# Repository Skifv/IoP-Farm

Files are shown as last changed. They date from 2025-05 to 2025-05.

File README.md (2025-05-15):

# IoP-Farm (Internet of Plants Farm)

## Проектная документация

### Содержание
1. [Задача проекта](#задача-проекта)
2. [Описание решения](#описание-решения)
3. [Аппаратная часть](#аппаратная-часть)
   - [Компоненты](#компоненты)
   - [Схема подключения](#схема-подключения)
4. [Программная часть](#программная-часть)
   - [Архитектура](#архитектура)
   - [Основные модули](#основные-модули)
5. [Производство](#производство)
   - [Использованные инструменты и оборудование](#использованные-инструменты-и-оборудование)
   - [Процесс сборки](#процесс-сборки)
6. [Трудности и проблемы](#трудности-и-проблемы)
7. [Результаты](#результаты)
8. [Дальнейшее развитие](#дальнейшее-развитие)

## Задача проекта

Создание компактной автоматизированной умной фермы для выращивания сельскохозяйственных культур с возможностью удаленного мониторинга и управления через мобильное приложение. Система должна обеспечивать автоматический полив, контроль микроклимата, освещения и передачу данных в режиме реального времени.

## Описание решения

IoP-Farm (Internet of Plants Farm) представляет собой полностью автоматизированную мини-ферму на базе микроконтроллера ESP32, объединяющую аппаратную и программную части в единую экосистему для выращивания растений.

Основные функциональные возможности:

- **Автоматический полив**: система на основе данных о влажности почвы и расписания включает насос R385, который подает воду в количестве, необходимом конкретной культуре.

- **Контроль температуры**: датчики DHT22 и DS18B20 следят за температурой воздуха и почвы, а система автоматически включает тепловую лампу при падении температуры ниже заданного порога.

- **Управление освещением**: фитолента включается и выключается по заданному расписанию, обеспечивая оптимальный световой режим для растений.

- **Мониторинг уровня воды**: ультразвуковой датчик HC-SR04 контролирует уровень воды в резервуаре, предупреждая о необходимости его пополнения.

- **WiFi и MQTT-интеграция**: система подключается к домашней сети WiFi и отправляет данные на MQTT-сервер, что позволяет управлять фермой удаленно.

- **Мобильное приложение**: специальное Android-приложение позволяет в реальном времени мониторить все показатели, менять настройки и управлять исполнительными устройствами.

## Аппаратная часть

### Компоненты

#### Микроконтроллер
- **ESP32 WROOM 32**: 32-битный двухъядерный микроконтроллер с WiFi и Bluetooth, 4 МБ Flash-памяти, 520 КБ SRAM

#### Датчики
- **DHT22**: цифровой датчик температуры и влажности воздуха
- **DS18B20**: цифровой датчик температуры с водонепроницаемым корпусом для измерения температуры почвы
- **HC-SR04**: ультразвуковой датчик расстояния для контроля уровня воды в резервуаре
- **FC-28**: аналоговый датчик влажности почвы
- **KY-018**: фоторезистор для определения уровня освещенности
- **YFS401**: датчик расхода воды (расходомер)

#### Исполнительные устройства
- **Насос R385**: водяной насос для полива растений
- **Тепловая лампа**: для поддержания нужной температуры воздуха
- **Фитолента (LED)**: специализированное освещение для оптимального роста растений

#### Блок питания
- **12V адаптер питания** для ESP32 через DC-Jack, насоса и всех остальных устройств при помощи DC-DC преобразователей.

#### Корпус
- Корпус из прозрачного акрилового стекла (оргстекла) толщиной 6 мм
- 3D-печатные крепления и держатели для датчиков и актуаторов
- Ведро для воды, помещенное в пластиковую тонкую оболочку

Альтернативный текст

### Схема подключения

Датчики и актуаторы подключены к ESP32 согласно схеме, описанной в файле схемы и в заголовочных файлах исходного кода. 

## Программная часть

### Архитектура

Программное обеспечение IoP-Farm построено на принципах объектно-ориентированного программирования и модульной архитектуры. Это позволяет легко расширять функциональность и добавлять новые компоненты без изменения основной структуры - стандартные принципы ООП.

### Основные модули

1. **Датчики (sensors)**: Абстракция всех датчиков через интерфейс `ISensor`, который определяет единый метод получения данных. Каждый датчик реализован как отдельный класс, наследующийся от базового интерфейса.

2. **Актуаторы (actuators)**: Все исполнительные устройства реализованы через интерфейс `IActuator`. Включает в себя насос, тепловую лампу и фитоленту.

3. **Стратегии (strategies)**: Определяют логику работы актуаторов на основе данных от датчиков и расписания. Реализованы стратегии полива, нагрева и освещения. Позволяют легко масшабировать систему и являются основой нашей экосистемы.

4. **Менеджеры (managers)**:
   - **WiFiManager**: Управление WiFi-соединением, создание точки доступа при необходимости
   - **MQTTManager**: Подключение к MQTT-брокеру, отправка/получение сообщений
   - **ConfigManager**: Управление конфигурацией в SPIFFS, загрузка дефолтных настроек
   - **OTAManager**: Обеспечение обновления прошивки по воздуху
   - **WebServerManager**: Веб-интерфейс для конфигурации

5. **Логирование**: Система логирования с различными уровнями, форматтерами и транспортами (Serial, MQTT).

6. **Мобильное приложение**: Android-приложение для управления фермой, разработанное на Java, взаимодействующее с системой через MQTT.

## Производство

### Использованные инструменты и оборудование

- **3D-принтеры** для изготовления креплений, держателей и функциональных деталей
- **Лазерные резаки** для точной обработки акрилового стекла
- **Паяльная станция** для монтажа электронных компонентов
- **Струбцины** для склейки оргстекла дихлорэтаном
- **Ручной инструмент** (отвертки, плоскогубцы, кусачки и т.д.)
- **Мультиметр** для тестирования электрических цепей

## Трудности и проблемы

В процессе разработки и реализации проекта мы столкнулись с несколькими серьезными проблемами:

1. **Проблемы с 3D-печатью**: Постоянно приходилось переставлять 3D-принтеры на печать из-за проблем с первым слоем. Это значительно замедлило процесс изготовления деталей и корпуса.

2. **Ограничения пуш-уведомлений**: Не удалось реализовать пуш-уведомления на Android из-за того, что они зависят от сервисов Google Firebase Cloud Messaging (FCM), доступ к которым ограничен в России из-за санкций. Android запрещает фоновым приложениям выполнять определенные действия, если они не используют официальные API Google.

3. **Трудности с микроконтроллерами**: Изначально проект планировалось реализовать на STM32, но из-за отмены курса по микроконтроллерам и отсутствия достаточного опыта работы с ними, более двух недель ушло на попытки настроить STM32. В итоге было принято решение перейти на более удобную в разработке платформу ESP32.

4. **Интеграция аппаратной и программной частей**: Потребовалось много времени на отладку взаимодействия между датчиками, ESP32 и исполнительными устройствами, особенно в части обработки ошибок и надежности системы.

## Результаты

В результате проекта была создана полностью функциональная автоматизированная мини-ферма с возможностью удаленного управления. Система обеспечивает:

- Полностью автоматический полив на основе показаний датчиков влажности почвы
- Контроль и поддержание температуры окружающей среды
- Управление освещением по расписанию
- Удобный мониторинг всех показателей через мобильное приложение
- Возможность ручного управления всеми исполнительными устройствами
- Настройку и конфигурирование системы без необходимости физического доступа к устройству

## Дальнейшее развитие

Планы по дальнейшему развитию проекта включают:

1. **Масштабирование системы** для поддержки нескольких ферм с централизованным управлением
2. **Расширение набора датчиков** (pH почвы, CO2, содержание минералов)
3. **Улучшение** внешнего вида приложения

---

Проект IoP-Farm демонстрирует, как современные технологии могут быть применены для решения практических задач в области сельского хозяйства и домашнего растениеводства, обеспечивая оптимальные условия выращивания с минимальным участием человека.

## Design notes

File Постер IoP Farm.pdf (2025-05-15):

# IoP Farm

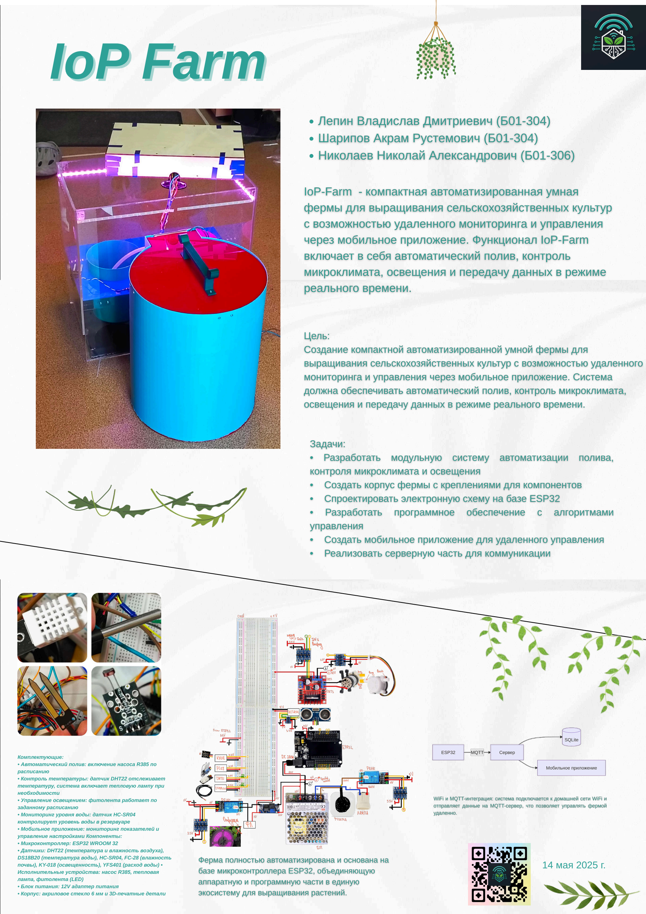
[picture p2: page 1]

14 мая 2025 г.

Комплектующие:

- Автоматический полив: включение насоса R385 по

расписанию

- Контроль температуры: датчик DHT22 отслеживает

температуру, система включает тепловую лампу при

необходимости

- Управление освещением: фитолента работает по

заданному расписанию

- Мониторинг уровня воды: датчик HC-SR04

контролирует уровень воды в резервуаре

- Мобильное приложение: мониторинг показателей и

управление настройками Компоненты:

- Микроконтроллер: ESP32 WROOM 32
- Датчики: DHT22 (температура и влажность воздуха),

DS18B20 (температура воды), HC-SR04, FC-28 (влажность

почвы), KY-018 (освещенность), YFS401 (расход воды) •

Исполнительные устройства: насос R385, тепловая

лампа, фитолента (LED)

- Блок питания: 12V адаптер питания
- Корпус: акриловое стекло 6 мм и 3D-печатные детали

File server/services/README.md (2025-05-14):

Ключевые возможности
- Сбор данных с ESP32-устройств в реальном времени
- Хранение в локальной БД (data.db) с историей показаний
- Интерфейс API на основе TCP и MQTT, включает:
    - Логирование в syslog и файлы (/var/log/)
    - Автозапуск через systemd

```mermaid
graph TD
    A[Датчики ESP32] -->|MQTT| B(MQTT-брокер)
    B --> C[IoP-Server]
    C --> D[(SQLite БД)]
    
    C --> F[TCP API]
    
    F --> G

```

Также необходимо запустить mqtt-server(например mosquitto) на 1883, а также снять ограничения файервола.

Службы сервера:
- data.service (services/data_server_farm/) 
    - Подписывается на топик /farm$id$/data
    - Записывает данные от MQTT-брокера в БД(data.db)
- logger.service (services/farm_logger/)
    - Подписывается на топик /farm$id$/log
    - Записывает данные от MQTT-брокера в syslog
    - Для просмотра логов:
- logs.service (/services/logs_to_phone/)
    - Пересылает на мобильное устройство отчёт по всем показаниям фермы
    - Отправляются все отчёты, удовлетворяющие показателям "unix_time_from" - "unix_time_to"
    - В случае ошибок, неправильного формата, отправляется последняя запись
    - Для просмотра логов:
- config.service (/services/control_phone_config)
    - Принимает подключение от мобильного устройства, получает конфиг параметров сенсоров
    - Публикует в топик /farm$id$/config
- command.service (services/command_services)
    - Принимает подключение от мобильного устройства, получает команду, к-ую срочно нужно обработать на ферме
    - Публикует в топик /farm$id$/command
    
Просмотр логов одной конкретной службы:
```sh
journalctl -u $name$.service
```

Просмотреть статус + логи/добавление в автозагрузку/удаление/старт/остановка конкретной службы:
```sh
systemctl status/enable/disable/start/stop $name$.service
```

Сделать для всех служб сразу:
```sh
./farmctl status/enable/disable/start/stop
```
ВАЖНО!
Если службы НЕ РАБОТАЮТ/ОСТАНОВЛЕНЫ можно запустить вручную бинарные файлы(ОПАСНО):
В папке необходимой службы запускаем компиляцию(sh файл) и исполняем:
```sh
sh data.sh/logger.sh/logs.sh/config.sh/command.sh

# Без прикрепления к commandline в фоновом режиме
nohup DATA/LOGGER/LOGS/CONFIG/COMMAND &
```
Либо же централизовано в папке services компиляция + исполнение:
```sh
sh compile_and_run.sh
```
Удаление фоновых процессов:
```sh
sh delete_trash.sh
```

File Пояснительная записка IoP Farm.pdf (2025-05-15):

## Краткая пояснительная записка к проекту

## “Компактная умная ферма с WiFi-управлением”

## 1 Состав проектной команды и вклад участников

- Лепин Владислав Дмитриевич (Б01-304) — программирование ESP32, разработка

архитектуры программной части, пайка, проектирование и сборка схемы, подготовка презентации, дизайн корпуса.

- Шарипов Акрам Рустемович (Б01-304) — разработка Android-приложения на Java,

проектирование всех 2D и 3D моделей, пайка электронных компонентов.

- Николаев Николай Александрович (Б01-306) — разработка серверной части для

коммуникации между фермой и приложением, сборка конструкции фермы.

## 2 Причины выбора проекта

Основная мотивация — создание практически полезного устройства для повседневного использования, а не просто демонстрационного прототипа. Автоматизированная ферма решает практическую задачу обеспечения растений оптимальными условиями с минимальным участием человека. Проект позволил применить знания из программирования, электроники и 3D-моделирования.

## 3 Цель и задачи проекта

Цель: создание компактной автоматизированной умной фермы для выращивания сельскохозяйственных культур с возможностью удаленного мониторинга и управления через мобильное приложение. Система должна обеспечивать автоматический полив, контроль микроклимата, освещения и передачу данных в режиме реального времени.
Задачи:
- Разработать модульную систему автоматизации полива, контроля микроклимата и освещения
- Создать корпус фермы с креплениями для компонентов
- Спроектировать электронную схему на базе ESP32
- Разработать программное обеспечение с алгоритмами управления
- Создать мобильное приложение для удаленного управления
- Реализовать серверную часть для коммуникации

## 4 Описание продукта

IoP-Farm (Internet of Plants Farm) — автоматизированная мини-ферма на базе ESP32

с функциями:

- Автоматический полив: включение насоса R385 по расписанию
- Контроль температуры: датчик DHT22 отслеживает температуру, система включает тепловую лампу при необходимости
- Управление освещением: фитолента работает по заданному расписанию
- Мониторинг уровня воды: датчик HC-SR04 контролирует уровень воды в резервуаре
- Мобильное приложение: мониторинг показателей и управление настройками

Компоненты:

- Микроконтроллер: ESP32 WROOM 32
- Датчики: DHT22 (температура и влажность воздуха), DS18B20 (температура воды), HC-SR04, FC-28 (влажность почвы), KY-018 (освещенность), YFS401 (расход воды)
- Исполнительные устройства: насос R385, тепловая лампа, фитолента (LED)
- Блок питания: 12V адаптер питания
- Корпус: акриловое стекло 6 мм и 3D-печатные детали

## 5 Процесс решения поставленных задач

### 5.1 Программная часть

Программное обеспечение построено на принципах ООП и модульной архитектуры:

- Датчики: абстракция через интерфейс ISensor
- Актуаторы: все устройства реализованы через интерфейс IActuator
- Стратегии: определяют логику работы на основе данных от датчиков
- Менеджеры: WiFiManager, MQTTManager, ConfigManager, OTAManager, WebServerManager, SensorsManager, ActuatorsManager
- Мобильное приложение: Java-приложение для Android, взаимодействующее через сервер по TCP. Сервер взаимодействует с фермой по MQTT

Все менеджеры, взаимодействуя между собой, управляют работой фермы.
Исходный код проекта доступен в репозитории: https://github.com/Skifv/IoP-Farm

### 5.2 Аппаратная часть

Плоские детали корпуса изготовлены лазерной резкой акрилового стекла, сложные формы — 3D-печатью. Соединение деталей выполнено дихлорэтаном с фиксацией струбцинами. Электронные компоненты соединены по разработанной схеме и подсоединены к ESP32.
Все спроектированные модели доступны в репозитории: https://github.com/Skifv/

IoP-Farm (https://github.com/Skifv/IoP-Farm)

## 6 Анализ существующих аналогов

Найденные нами аналоги имели схожий функционал, но небольшие различия: наличие/отсутствие полива/обогрева/освещения по расписанию/команде. Также в некоторых

отсутствует контроль уровня воды или расхода воды. В одном из аналогов есть камера и визуальный контроль растений.
Отличительные особенности нашего проекта:
- Комплексная автоматизация: полив, обогрев и освещение в одной системе. Ни один из найденных нами аналогов не включал такого разнообразия компонентов
- Контроль расхода воды для точного полива заданного объема. В остальных проектах полив осуществляется на заданный интервал времени, что, безусловно, имеет большие минусы
- Модульная архитектура, позволяющая легко расширять функциональность
- Возможность OTA-обновления программного обеспечения

Здесь можно найти проанализированные аналоги:
1. https://github.com/sunny-zuo/smart-garden
2. https://github.com/fruxefarms/FruxePi
3. https://github.com/PatrickHallek/automated-irrigation-system

## 7 Процесс проектирования и изготовления

Процесс создания IoP-Farm включает в себя 3 этапа (то, что программирование находится на третьем месте, не определяет его порядок):

1. Проектирование:
- Разработка архитектуры системы, определение компонентов
- Проектирование электрической схемы подключения
- Моделирование деталей корпуса в FreeCAD и 3D-моделей в Компас 3D

2. Изготовление:
- Лазерная резка акрилового стекла, 3D-печать креплений
- Сборка корпуса с использованием дихлорэтана
- Монтаж электронных компонентов и пайка
3. Программирование:
- Разработка ПО для ESP32 на C++
- Создание Android-приложения на Java
- Разработка сервера на C++
- Настройка MQTT-брокера

## 8 Процесс тестирования и его результаты

Тестирование проводилось при помощи разработанной системы дистанционного логирования процессов, происходящих на микроконтроллере.
Использовались команды с мобильного приложения и анализировались логи от фермы через сервер. Результаты показали стабильную работу системы:
- Полив активируется при помощи команд, расписание работает корректно
- Система освещения и обогрева работают согласно выстроенным настройкам
- Показания датчиков корректно отображаются в приложении

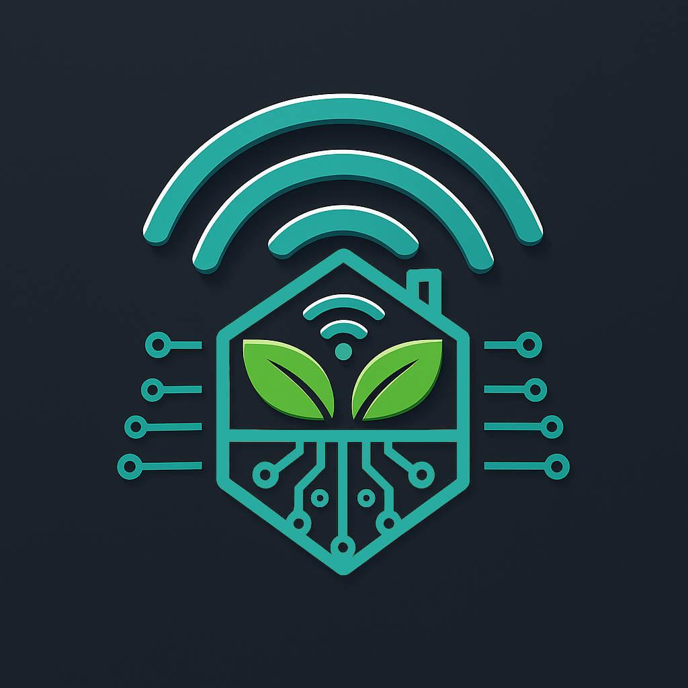
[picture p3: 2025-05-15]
Логотип.png

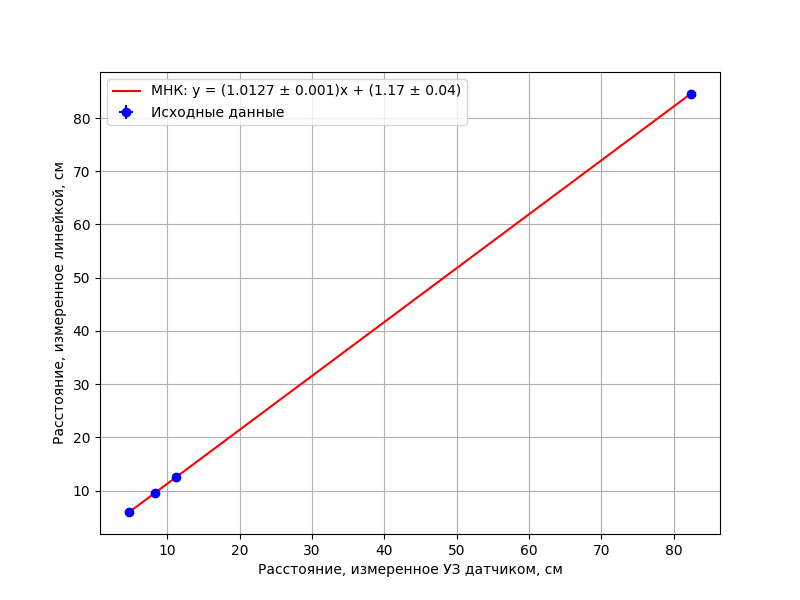
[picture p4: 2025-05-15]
Калибровка ультразвукового датчика.png

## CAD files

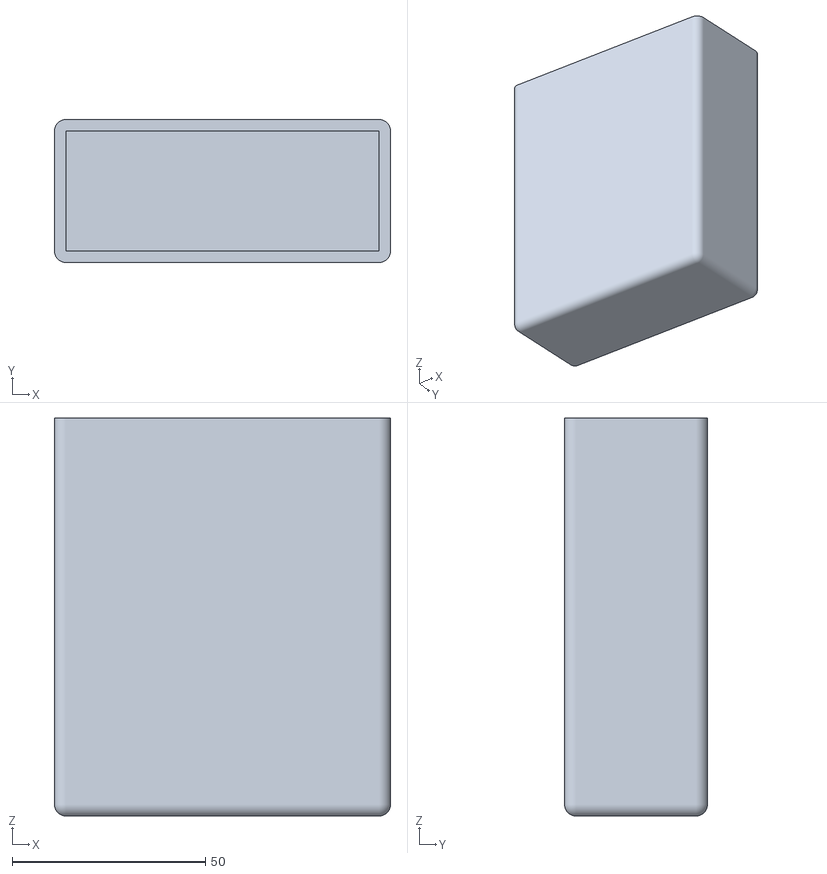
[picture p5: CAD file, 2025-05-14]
3DP_and_laser/transkeeper.stl
87.0 x 37.0 x 103.0

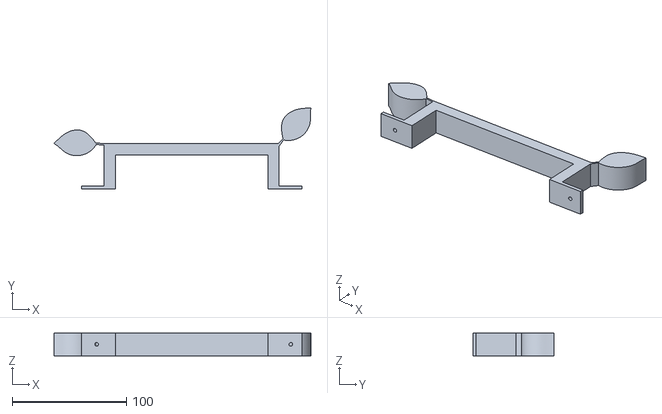
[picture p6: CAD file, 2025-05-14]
3DP_and_laser/handhold.stl
225.1 x 71.3 x 20.0

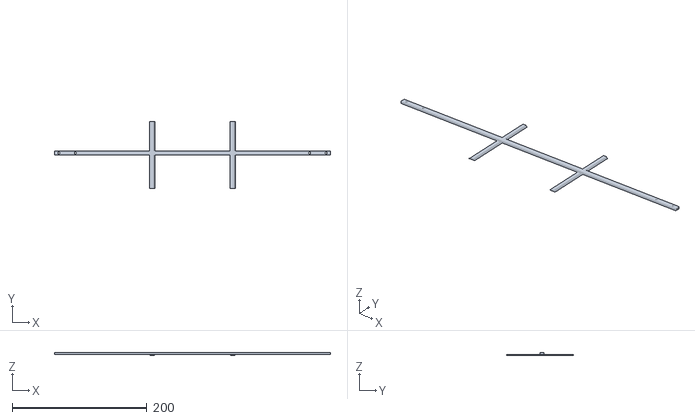
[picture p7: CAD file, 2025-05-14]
3DP_and_laser/rails.stl
410.0 x 100.0 x 5.00

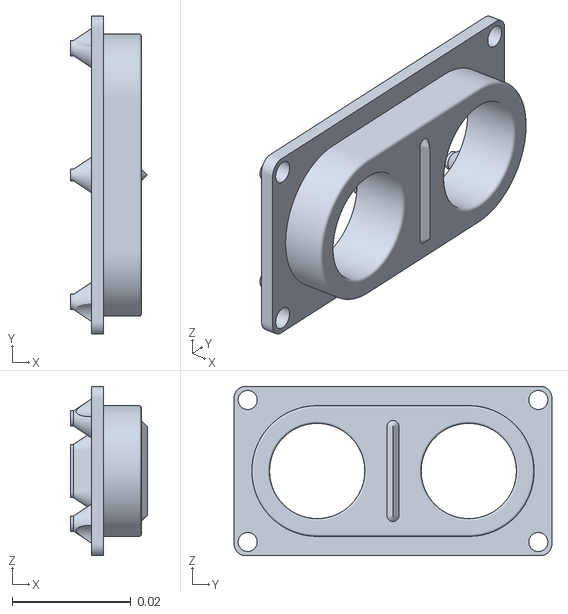
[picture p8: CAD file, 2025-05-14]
3DP_and_laser/HC-SR04_holder.stl
0.0129 x 0.0535 x 0.0285

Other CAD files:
3DP_and_laser/farmbox.stl

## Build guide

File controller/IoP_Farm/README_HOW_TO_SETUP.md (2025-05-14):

# IoP-Farm: Умная автоматизированная ферма на ESP32

**Версия:** 1.0  
**Дата:** 10.05.2025

---

## Оглавление

- [О проекте](#о-проекте)
- [Краткие возможности](#краткие-возможности)
- [Быстрый старт: PlatformIO environments и первичная загрузка](#быстрый-старт-platformio-environments-и-первичная-загрузка)
- [Архитектура и основные компоненты](#архитектура-и-основные-компоненты)
- [Изменяемые параметры в constants.h](#изменяемые-параметры-в-constantsh)
- [Сервер-посредник и хранение данных](#сервер-посредник-и-хранение-данных)
- [Управление с телефона и мониторинг через Android-приложение IoP Farm](#управление-с-телефона-и-мониторинг-через-android-приложение-iop-farm)
- [OTA-обновления](#ota-обновления)
- [Масштабирование и расширение](#масштабирование-и-расширение)
- [Безопасность](#безопасность)
- [FAQ и советы](#faq-и-советы)
- [Важные замечания](#важные-замечания)
- [Контакты и поддержка](#контакты-и-поддержка)

---

## О проекте

**IoP-Farm** — это модульная система для автоматизации полива домашних растений на базе ESP32. Система поддерживает работу с различными датчиками и исполнительными устройствами, интеграцию с WiFi/MQTT, удаленное управление и обновление прошивки по воздуху (OTA). Проект ориентирован на максимальную надежность, расширяемость и простоту первичной настройки.

---

## Краткие возможности

- Автоматический полив по расписанию и объему воды
- Контроль температуры и автоматическое управление нагревом
- Управление освещением по расписанию
- Поддержка WiFi 2.4 ГГц (WPA2/WPA3, STA и точка доступа) для управления с телефона.
- MQTT-интеграция для сбора данных и управления
- Гибкая система конфигурирования (web-интерфейс, WiFiManager, настройка с приложения на Android)
- OTA-обновления (PlatformIO, web-интерфейс, WiFiManager)
- Логирование (Serial, MQTT)
- Модульная архитектура: легко добавлять новые датчики, актуаторы, стратегии
- Хранение всех настроек в энергонезависимой памяти (SPIFFS), автоматическая загрузка последних/дефолтных конфигов в зависимости флага компиляции
- Безопасность: аутентификация web-интерфейса при загрузки прошивки по OTA
- Масштабируемость: поддержка новых топиков MQTT, датчиков и актуаторов, стратегий работы

---

## Быстрый старт: PlatformIO environments и первичная загрузка

### Как устроен platformio.ini

В проекте определено несколько сред (environments) для разных сценариев работы и отладки. Это позволяет гибко управлять процессом прошивки, конфигурирования и обновления устройства.

#### Основные environments:

- `[env:esp32doit-devkit-v1]` — **Штатный режим без лишних логов**. Используется для финальной эксплуатации, когда не требуется подробная отладка.
- `[env:debug]` — **Режим с подробным логированием** (рекомендуется для разработки и диагностики). Выводит максимум информации в Serial и MQTT.
- `[env:load_default_configs]` — **Первичная загрузка**. Используется только при первом запуске нового микроконтроллера или для сброса к заводским настройкам. Загружает дефолтные конфиги и включает расширенное логирование.
- `[env:debugOTA_320WiFi5]`, `[env:debugOTAVenom]` — **OTA-обновления через PlatformIO**. Примеры для разных сетей. Для своей сети скопируйте любой из этих блоков, поменяйте `upload_port` на IP вашей ESP32 в локальной сети, к которой она подключается и (если вы выставили нестандартный пароль) `upload_flags` с новым паролем.

Выбор environment происходит на панели управления platformio.ini в нижней части экрана.

#### Пример добавления своей среды для OTA:

```ini
[env:debugOTA_MyNetwork]
platform = espressif32
board = esp32doit-devkit-v1
framework = arduino
upload_protocol = espota
upload_port = <IP_ESP32>
upload_flags = 
    --auth=<ваш_пароль>
; остальные параметры аналогичны debug
```

Для загрузки прошивки по ArduinoOTA через созданную среду необходимо выставить в настройках platformio.ini (на панели управления в нижней части экрана) в качестве порта локальный IP ESP32 в вашей сети, компьютер при этом тоже должен быть подключен к тому же WiFi. Если все было выставлено, убедитесь, что ESP32 подключен к данному WiFi и загрузите прошивку, нажав Upload на панели управления platformio.ini.

### Порядок действий при первичной загрузке

1. **Клонируйте репозиторий и установите PlatformIO.**
2. **Загрузка файлов конфигурации в SPIFFS**
   - После любой смены конфигов или при первом запуске обязательно загрузите все файлы из папки `data/` на ESP32:
     ```
     pio run --target uploadfs
     ```
   - Это создаст в SPIFFS все необходимые конфиги (`data.json`, `config.json`, `mqtt.json`, `passwords.json` и их дефолтные версии).
3. **Загрузка дефолтных конфигов**
   - Перед началом работы необходимо загрузить файлы из папки `data/` в энергонезависимую память SPIFFS. См. пункт 2.
   - Затем обязательно используйте `[env:load_default_configs]` для самой первой прошивки нового микроконтроллера.
   - Это обеспечит корректную инициализацию всех файлов настроек во Flash.
   - После этого рекомендуется сразу перейти на `[env:debug]` для дальнейшей работы. 
4. **Подключитесь к точке доступа ESP32 и настройте WiFi/MQTT через портал.**
5. **Проверьте работу системы через приложение IoP Farm.**

**Перепрошивка**
   - Для обычной перепрошивки используйте `[env:debug]` (рекомендуется) или `[env:esp32doit-devkit-v1]` (минимум логов).
   - Для OTA-обновлений используйте соответствующую OTA-среду или создайте свою.
   - Для других способов перепрошивки (по сети) см. раздел `OTA Обновления`.

---

## Архитектура и основные компоненты

### Датчики и исполнительные устройства

- **Датчики**: DHT22 (температура и влажность), DS18B20 (температура), HC-SR04 (уровень воды), FC-28 (влажность почвы), KY-018 (освещенность), YFS401 (расход воды).
- **Актуаторы**: насос R385, тепловая лампа, фитолента.
- **Схемы подключения**: см. заголовочный файл в `include/sensors/*.h`. Также см. `scheme.pdf`, в котором подробно нарисована понятная и подробная схема подключения.

### Менеджеры и их логика

- **WiFiManager** — автоматическое подключение к WiFi, поднятие точки доступа при ошибках, настройка через captive portal.
- **MQTTManager** — подключение к серверу, подписка на топики, обработка команд, автоматическое повторное подключение при разрыве соединения.
- **ConfigManager** — хранение всех настроек в SPIFFS, поддержка дефолтных и пользовательских конфигов.
- **OTAManager** — поддержка OTA-обновлений через PlatformIO.
- **WebServerManager** — web-интерфейс для OTA с аутентификацией.

---

## Изменяемые параметры в constants.h

Практически все базовые параметры системы вынесены в файл `include/config/constants.h`. Это позволяет гибко адаптировать прошивку под свои задачи без глубокого погружения в код. После изменения большинства параметров требуется пересборка и перепрошивка устройства.

### Примеры того, что можно менять:

- **Идентификатор устройства и MQTT**
  - `mqtt::DEFAULT_DEVICE_ID` — уникальный идентификатор вашей фермы для MQTT-топиков.
  - `mqtt::DEFAULT_HOST`, `mqtt::DEFAULT_PORT` — адрес и порт MQTT-брокера по умолчанию.
- **WiFi и точка доступа**
  - `wifi::DEFAULT_AP_NAME`, `wifi::DEFAULT_AP_PASSWORD` — имя и пароль точки доступа ESP32.
  - `wifi::DEFAULT_HOSTNAME` — имя устройства в сети.
  - Таймауты подключения, интервалы переподключения (`CONNECT_TIMEOUT`, `RECONNECT_RETRY_INTERVAL` и др.).
- **Пины подключения датчиков и актуаторов**
  - Все пины для датчиков (`sensors::pins::...`) и исполнительных устройств (`actuators::pins::...`).
  - Можно переназначить под свою разводку платы.
- **Калибровочные значения и параметры датчиков**
  - Например, `sensors::calibration::FC28_DRY_VALUE`, `YFS401_CALIBRATION_FACTOR`, `HCSR04_A`, `HCSR04_B` и др.
  - Позволяет точно откалибровать систему под вашу физическую установку.
- **Пороговые значения ошибок и "нет данных"**
  - `sensors::calibration::SENSOR_ERROR_VALUE`, `NO_DATA` — значения, которые система возвращает при ошибке или отсутствии данных.
- **Параметры стратегий управления**
  - В пространствах имен `strategies::irrigation`, `strategies::heating`, `strategies::lighting` можно изменить интервалы, гистерезисы, расписания и т.д.
- **Интервалы работы системы**
  - Например, `sensors::timing::DEFAULT_READ_INTERVAL` — период опроса датчиков.
  - `actuators::CHECK_INTERVAL` — частота проверки актуаторов.
- **Логгирование**
  - В пространстве имен `log::constants` можно изменить уровни логирования, цвета, буферы, минимальный уровень для отправки логов в MQTT и др.
- **Команды управления**
  - В enum `CommandCode` можно добавить или изменить коды команд для MQTT.
- **Параметры времени**
  - `time::DEFAULT_GMT_OFFSET`, `time::NTP_PERIOD` — часовой пояс и период синхронизации времени. По умолчанию выставлен GMT+3 (Москва).

### Как менять параметры

1. Откройте файл `include/config/constants.h` в редакторе.
2. Найдите нужный параметр (или используйте поиск по имени).
3. Измените значение на свое (например, смените пин, пароль, deviceId, калибровку).
4. Сохраните файл, пересоберите и перепрошейте проект.

**Важно:**
- После изменения параметров в constants.h всегда пересобирайте проект и загружайте новую прошивку на ESP32.
- Некоторые параметры (например, deviceId, пароли, пины) критичны для работы системы — меняйте их осознанно.
- Для изменения логина/пароля web-интерфейса используйте файл `passwords.json`.

---

## Сервер-посредник и хранение данных

Для повышения надежности, безопасности и удобства работы в системе IoP-Farm реализован собственный сервер-посредник. Он выполняет следующие функции:

- **Маршрутизация всех сообщений** между ESP32 (фермой) и мобильным приложением. Все сообщения MQTT-топиков (`config`, `data`, `command`, `logs`) проходят через сервер, что позволяет централизованно управлять обменом данными.
- **Хранение данных**: сервер сохраняет все показания датчиков, команды, логи и конфигурации в собственной базе данных. Это обеспечивает:
  - Мониторинг истории и анализ данных
  - Централизованный доступ к информации с разных устройств

### Службы сервера:
- data.service (services/data_server_farm/) 
    - Подписывается на топик /farm$id$/data
    - Записывает данные от MQTT-брокера в БД(data.db)
- logger.service (services/farm_logger/)
    - Подписывается на топик /farm$id$/log
    - Записывает данные от MQTT-брокера в syslog
    - Для просмотра логов:
- logs.service (/services/logs_to_phone/)
    - Пересылает на мобильное устройство отчёт по всем показаниям фермы
    - Отправляются все отчёты, удовлетворяющие показателям "unix_time_from" - "unix_time_to"
    - В случае ошибок, неправильного формата, отправляется последняя запись
    - Для просмотра логов:
- config.service (/services/control_phone_config)
    - Принимает подключение от мобильного устройства, получает конфиг параметров сенсоров
    - Публикует в топик /farm$id$/config
- command.service (services/command_services)
    - Принимает подключение от мобильного устройства, получает команду, к-ую срочно нужно обработать на ферме
    - Публикует в топик /farm$id$/command
    
Просмотр логов одной конкретной службы:
```sh
journalctl -u $name$.service
```

Просмотреть статус + логи/добавление в автозагрузку/удаление/старт/остановка конкретной службы:
```sh
systemctl status/enable/disable/start/stop $name$.service
```

Сделать для всех служб сразу:
```sh
./farmctl status/enable/disable/start/stop
```
ВАЖНО!
Если службы НЕ РАБОТАЮТ/ОСТАНОВЛЕНЫ можно запустить вручную бинарные файлы(ОПАСНО):
В папке необходимой службы запускаем компиляцию(sh файл) и исполняем:
```sh
sh data.sh/logger.sh/logs.sh/config.sh/command.sh

# Без прикрепления к commandline в фоновом режиме
nohup DATA/LOGGER/LOGS/CONFIG/COMMAND &
```
Либо же централизовано в папке services компиляция + исполнение:
```sh
sh compile_and_run.sh
```
Удаление фоновых процессов:
```sh
sh delete_trash.sh
```

---

## Управление с телефона и мониторинг через Android-приложение IoP Farm

Система IoP-Farm поддерживает полноценное управление и мониторинг с мобильного устройства благодаря специально разработанному Android-приложению. Это позволяет:

- **Просматривать показания всех датчиков** (температура, влажность, уровень воды, освещенность и др.) в реальном времени прямо на экране телефона.
- **Управлять исполнительными устройствами** (насос, лампа нагрева, фитолента) дистанционно — запускать/останавливать вручную или по расписанию.
- **Менять параметры конфигурации** (например, расписание полива, целевые значения температуры, объем воды и т.д.) без необходимости перепрошивки устройства.

### Как работает обмен данными

Вся коммуникация между ESP32 и приложением строится на протоколе MQTT с посредником в виде сервера. Для каждого устройства (фермы) используется уникальный идентификатор `farmId` (например, `farm001`).

- **Загрузка конфигурации**: приложение получает настройки из топика `{farmId}/config`.
- **Мониторинг данных**: все показания датчиков публикуются устройством в топик `{farmId}/data`.
- **Управление и команды**: приложение отправляет команды в топик `{farmId}/command`, которые тут же обрабатываются системой.
- **Логи и диагностика**: все события, ошибки и служебные сообщения отправляются в топик `{farmId}/logs`.

### Требования

- ESP32 и телефон должны быть подключены к сети. 

**Преимущества:**
- Не требуется физический доступ к устройству для настройки и управления.
- Все изменения применяются мгновенно, без перепрошивки.
- Удобный мониторинг и диагностика в одном месте.

---

## OTA-обновления

- **PlatformIO OTA**: используйте соответствующую среду, будьте в одной сети с ESP32, пароль по умолчанию `12345678`.
- **Web-интерфейс**: доступен по адресу ESP32, требуется аутентификация (логин/пароль из `passwords.json`. Для его изменения необходимо будет заново загрузить дефолтные настройки, см. `Загрузка файлов конфигурации в SPIFFS`).
- **WiFiManager**: при потере или отсутствии связи ESP32 поднимает точку доступа, там же можно обновить прошивку в `upload`. Пароль по умолчанию для WiFiManager `12345678`, можно изменить в файле `constants.h`. Точка доступа ESP32 будет высвечена в списке доступных WiFi-сетей на вашем устройстве.

---

## Масштабирование и расширение

- Добавляйте новые датчики/актуаторы через наследование от `ISensor`/`IActuator`.
- Новые стратегии — через наследование от `IActuatorStrategy` и регистрацию в менеджере.
- Для новых топиков MQTT — пропишите их в `constants.h` и настройте обработку в `MQTTManager`.
- Для поддержки нескольких ферм используйте уникальный `deviceId`, изменив его в `constants.h`.
- Логи выводятся в Serial и/или отправляются на MQTT. Тип логгирования можно изменить в самом начале `main.cpp`, создав нужный логгер при помощи фабрики. Вы можете добавить свой способ форматирования сообщений и свой транспорт для логгирования, наследуя их от соответствующих абстрактных классов.

---

## FAQ и советы

- **Нужно ли каждый раз подключаться к WiFi?** Нет, только при первом запуске или сбросе настроек. Для работы актуаторов требуется хотя бы однократная синхронизация времени через интернет.
- **Что делать, если настройки сбились?** Можно загрузить новые настройки из приложения (предпочтительно). Если с этим возникла проблема, загрузите дефолтные файлы через `pio run --target uploadfs` (см. `Загрузка файлов конфигурации в SPIFFS`) и повторите настройку.
- **Почему я не получаю данные от расходометра?** Расходомер и не отправляет данные на сервер, он используется только насосом для корректного полива. Вы можете отследить показания расходометра в логах во время полива.

---

## Важные замечания

- Для корректной работы актуаторов требуется хотя бы однократная синхронизация времени через WiFi.
- Все схемы подключения и калибровки описаны в заголовочных файлах датчиков и нарисованы в scheme.pdf.
- Дефолтные файлы конфигурации обязательны для первого запуска!
- Светодиод на плате сигнализирует о проблемах с WiFi/MQTT (горит — нет связи с WiFi или MQTT, либо происходит подключение к WiFi).
- Данные с датчиков: `-50` — нет данных, `-100` — ошибка чтения. Данные константы можно изменить в `constants.h`.
- Для корректной работы датчиков их необходимо откалибровать:
**FC-28**: калибруется по сухой и влажной почве (см. `FC28.h`).
**HC-SR04**: требует калибровки коэффициентов (использована МНК-калибровка, см. `HCSR04.h`).
**YFS401**: калибруется по количеству импульсов на литр (см. `YFS401.h`).

---

## Контакты и поддержка

Если у вас возникли вопросы или предложения по развитию проекта — создайте issue или pull request в репозитории.

---

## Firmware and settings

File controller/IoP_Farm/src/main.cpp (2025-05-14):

#include <Arduino.h>
#include <memory>
#include <GyverNTP.h>

#include "network/wifi_manager.h"
#include "network/mqtt_manager.h"

#include "config/config_manager.h"
#include "config/constants.h"

#include "sensors/sensors_manager.h"
#include "logic/actuators_manager.h"

#include "utils/ota_manager.h"
#include "utils/web_server_manager.h"
#include "utils/logger_factory.h"
#include "utils/logger.h"
#include "utils/scheduler.h"

using namespace farm::config;
using namespace farm::config::sensors;
using namespace farm::log;
using namespace farm::net;
using namespace farm::sensors;
using namespace farm::utils;
using namespace farm::logic;

void allActuatorsOff();

// Создаем логгер с нужным уровнем и цветом в зависимости от режима компиляции
#if defined(IOP_DEBUG) && defined(COLOR_SERIAL_LOG)
auto logger = LoggerFactory::createColorSerialMQTTLogger(Level::Debug);
#elif defined(IOP_DEBUG)
auto logger = LoggerFactory::createSerialMQTTLogger(Level::Debug);
#elif defined(COLOR_SERIAL_LOG)
auto logger = LoggerFactory::createColorSerialMQTTLogger(Level::Info);
#else
auto logger = LoggerFactory::createSerialMQTTLogger(Level::Info);
#endif

// Получаем экземпляры синглтонов для всех менеджеров системы
std::shared_ptr<ConfigManager>    configManager    = ConfigManager::getInstance(logger);
std::shared_ptr<MyWiFiManager>    wifiManager      = MyWiFiManager::getInstance(logger);
std::shared_ptr<MQTTManager>      mqttManager      = MQTTManager::getInstance(logger);
std::shared_ptr<SensorsManager>   sensorsManager   = SensorsManager::getInstance(logger);
std::shared_ptr<OTAManager>       otaManager       = OTAManager::getInstance(logger);
std::shared_ptr<WebServerManager> webServerManager = WebServerManager::getInstance(logger);
std::shared_ptr<Scheduler>        schedulerManager = Scheduler::getInstance(logger);  
std::shared_ptr<ActuatorsManager> actuatorsManager = ActuatorsManager::getInstance(logger);

// Флаги для отслеживания инициализации NTP и актуаторов
bool ntpSynchronized = false;
bool actuatorsInitialized = false;
unsigned long startupTime = 0;

void setup() 
{
    allActuatorsOff(); // Гарантируем безопасный старт: все исполнительные устройства выключены

    Serial.begin(115200);
    delay(1000);

    pinMode(pins::LED_PIN, OUTPUT);
    digitalWrite(pins::LED_PIN, HIGH);

    startupTime = millis();
    
    logger->log(Level::Farm, "=== IoP-Farm начало работы ===");

    configManager->initialize();     

#ifdef IOP_DEBUG
    logger->log(Level::Debug, "Текущая файловая система SPIFFS:");
    configManager->printSpiffsInfo(); // Выводим структуру SPIFFS для отладки, печатается лишь в консоль
#endif

    wifiManager     ->initialize();  
    mqttManager     ->initialize();  
    sensorsManager  ->initialize();  
    otaManager      ->initialize();  
    
    webServerManager->enableAuth(true);
    webServerManager->initialize();  
    
    // Примечание: планировщик и менеджер актуаторов инициализируются лишь после синхронизации NTP Clock
    schedulerManager->initialize(time::DEFAULT_GMT_OFFSET);  
    actuatorsManager->initialize(); 
    
    // Демонстрация работы планировщика: событие через 30 секунд
    logger->log(Level::Debug, "[MAIN] Добавление тестового пустого события");
    schedulerManager->scheduleOnceAfter(30, []() {
        logger->log(Level::Info, "[MAIN] Тестовое событие выполнено через 30 секунд после запуска!");
    });

#ifdef USE_FREERTOS
    // Если используется FreeRTOS — запускаем задачу планировщика
    schedulerManager->startSchedulerTask(scheduler::SCHEDULER_TASK_PRIORITY, 
                                         scheduler::SCHEDULER_STACK_SIZE);
#endif
}

void loop() 
{
    wifiManager->maintainConnection();
    mqttManager->maintainConnection();

    // Контролируем синхронизацию времени через NTP
    if (NTP.tick()) 
    {
        if (!ntpSynchronized && schedulerManager->isNtpOnline()) {
            ntpSynchronized = true;
            unsigned long syncTime = (millis() - startupTime) / 1000;
            logger->log(Level::Info, 
                      "[NTP] NTP синхронизирован через %lu с. после запуска", 
                      syncTime);
            logger->log(Level::Info, "[MAIN] Текущее время: %s", NTP.toString().c_str());
        }
        else if (!ntpSynchronized)
        {
            logger->log(Level::Debug, "[MAIN] NTP не синхронизирован, текущее время: %s", NTP.toString().c_str());
            logger->log(Level::Debug, "[MAIN] ntpSynchronized: %d, ntpOnline: %d", ntpSynchronized, schedulerManager->isNtpOnline());
            NTP.updateNow();
        }
    }
    else if (!ntpSynchronized)
    {
        logger->log(Level::Debug, "[MAIN] NTP не синхронизирован, текущее время: %s", NTP.toString().c_str());
        logger->log(Level::Debug, "[MAIN] ntpSynchronized: %d, ntpOnline: %d", ntpSynchronized, schedulerManager->isNtpOnline());
        NTP.updateNow();
    }

#ifndef USE_FREERTOS
    // Планировщик событий вызывается вручную, если не используется FreeRTOS
    schedulerManager->checkSchedule();
#endif

    sensorsManager->loop();    // Опрос всех датчиков
    actuatorsManager->loop();  // Контроль состояния исполнительных устройств

    // Логируем момент инициализации актуаторов (однократно)
    if (!actuatorsInitialized && actuatorsManager->isInitialized()) {
        actuatorsInitialized = true;
        unsigned long initTime = (millis() - startupTime) / 1000;
        logger->log(Level::Info, 
                  "[ActuatorsManager] ActuatorsManager инициализирован через %lu с. после запуска", 
                  initTime);
    }

    otaManager->handle(); 
    webServerManager->handleClient();       

    delay(loop::DEFAULT_DELAY_MS); // Минимальная задержка для стабильности
}

void allActuatorsOff()
{
    // Программно выключаем все исполнительные устройства для предотвращения аварий при старте
    pinMode(actuators::pins::GROWLIGHT_PIN, OUTPUT);
    pinMode(actuators::pins::HEATLAMP_PIN, OUTPUT);
    pinMode(actuators::pins::PUMP_R385_FORWARD_PIN, OUTPUT);
    pinMode(actuators::pins::PUMP_R385_BACKWARD_PIN, OUTPUT);

    digitalWrite(actuators::pins::GROWLIGHT_PIN, LOW);
    digitalWrite(actuators::pins::HEATLAMP_PIN, LOW);
    digitalWrite(actuators::pins::PUMP_R385_FORWARD_PIN, LOW);
    digitalWrite(actuators::pins::PUMP_R385_BACKWARD_PIN, LOW);
}

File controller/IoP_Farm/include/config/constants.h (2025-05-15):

#ifndef FARM_CONFIG_CONSTANTS_H
#define FARM_CONFIG_CONSTANTS_H

#include <Arduino.h>

namespace farm::config
{
    // Типы конфигурационных файлов
    enum class ConfigType
    {
        Data,           // Данные от сенсоров ({device_id}/data)
        System,         // Конфигурация системы ({device_id}/config)
        Command,        // Команды управления ({device_id}/command)
        Mqtt,           // Конфигурация MQTT (не отправляется в топики! Нужно для сохранения в памяти)
        Log,            // Логи (/{device_id}/log). Это не файл. Нужно для получения MQTT топика
        Passwords       // Пароли и учетные данные (не отправляются в топики! Локальное хранение)
    };
    
    // Пути к файлам конфигурации
    namespace paths
    {
        constexpr const char* DATA_CONFIG      = "/data.json";     // Файл конфигурации с данными от датчиков
        constexpr const char* SYSTEM_CONFIG    = "/config.json";   // Файл основной конфигурации системы
        constexpr const char* COMMAND_CONFIG   = "/cmd.json";      // Файл с командами управления
        constexpr const char* MQTT_CONFIG      = "/mqtt.json";     // Файл конфигурации MQTT
        constexpr const char* PASSWORDS_CONFIG = "/passwords.json"; // Файл с паролями
        
        // Пути к дефолтным файлам конфигурации
        constexpr const char* DEFAULT_DATA_CONFIG      = "/default_data.json";     // Дефолтный файл с данными от датчиков
        constexpr const char* DEFAULT_SYSTEM_CONFIG    = "/default_config.json";   // Дефолтный файл системной конфигурации
        constexpr const char* DEFAULT_COMMAND_CONFIG   = "/default_cmd.json";      // Дефолтный файл с командами управления
        constexpr const char* DEFAULT_MQTT_CONFIG      = "/default_mqtt.json";     // Дефолтный файл конфигурации MQTT
        constexpr const char* DEFAULT_PASSWORDS_CONFIG = "/default_passwords.json"; // Дефолтный файл с паролями
    }

    // Константы для планировщика задач и FreeRTOS
    namespace scheduler
    {
        // Приоритеты задач
        constexpr uint8_t DEFAULT_TASK_PRIORITY = 2;    // Приоритет задачи по умолчанию
        constexpr uint8_t SCHEDULER_TASK_PRIORITY = 1;  // Рекомендуемый приоритет задачи планировщика
        
        // Размеры стека задач
        constexpr uint32_t DEFAULT_STACK_SIZE = 2048;   // Стандартный размер стека для простых задач
        constexpr uint32_t SCHEDULER_STACK_SIZE = 4096; // Размер стека для задачи планировщика
        
        // Временные интервалы
        constexpr uint32_t DEFAULT_CHECK_INTERVAL_MS = 100;  // Интервал проверки расписания по умолчанию (мс)
        constexpr uint32_t TASK_STOP_TIMEOUT_MS = 1000;     // Таймаут ожидания остановки задачи (мс)
        constexpr uint32_t TASK_STOP_CHECK_INTERVAL_MS = 100; // Интервал проверки остановки задачи (мс)
        
        // Прочие константы
        constexpr uint32_t TEST_EVENT_DELAY_SEC = 60;    // Задержка для тестового события (сек)
        constexpr uint8_t MAX_STOP_ATTEMPTS = 10;        // Максимальное количество попыток остановки задачи
    }

    // Константы для MQTT
    namespace mqtt
    {
        constexpr int16_t DEFAULT_PORT = -1;                  // Порт по умолчанию (-1 означает, что порт не назначен)
        constexpr const char* DEFAULT_HOST = "";              // Хост по умолчанию (пустая строка означает, что хост не назначен)
        
        constexpr const char* DEFAULT_DEVICE_ID = "farm001";  // ID устройства по умолчанию
        constexpr uint8_t DEVICE_ID_MAX_LENGTH = 32;      // Максимальная длина имени устройства
        
        // Суффиксы топиков
        constexpr const char* DATA_SUFFIX    = "/data";          // Суффикс для топика данных
        constexpr const char* CONFIG_SUFFIX  = "/config";      // Суффикс для топика конфигурации
        constexpr const char* COMMAND_SUFFIX = "/command";    // Суффикс для топика команд
        constexpr const char* LOG_SUFFIX     = "/log";         // Суффикс для топика логов

        // Константы для работы с MQTT подключением
        constexpr unsigned long CHECK_INTERVAL = 5000;           // 5 секунд между проверками соединения
        constexpr uint8_t MAX_RECONNECT_ATTEMPTS = 1;           // Максимальное количество попыток переподключения
        constexpr unsigned long RECONNECT_RETRY_INTERVAL = 10000; // 10 секунд между попытками переподключения
        
        // Уровни QoS (Quality of Service)
        constexpr uint8_t QOS_0 = 0;  // At most once - сообщение доставляется максимум один раз (или не доставляется вообще)
        constexpr uint8_t QOS_1 = 1;  // At least once - сообщение доставляется минимум один раз (возможны дубликаты)
        constexpr uint8_t QOS_2 = 2;  // Exactly once - сообщение доставляется ровно один раз (без дубликатов)
    }
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

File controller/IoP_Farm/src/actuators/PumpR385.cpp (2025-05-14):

#include "actuators/PumpR385.h"

namespace farm::actuators
{
    using namespace farm::log;
    using namespace farm::config::actuators;
    using namespace farm::config::sensors::calibration; 
    
    PumpR385::PumpR385(std::shared_ptr<log::ILogger> logger, uint8_t forwardPin, uint8_t backwardPin)
        : forwardPin(forwardPin),
          backwardPin(backwardPin),
          isForwardDirection(true)
    {
        this->logger = logger;
        
        setActuatorName(names::PUMP_R385);
        setActuatorType(types::WATER_PUMP);
    }
    
    PumpR385::~PumpR385()
    {
        if (isOn)
        {
            turnOff();
        }
    }
    
    bool PumpR385::initialize()
    {
        if (forwardPin == UNINITIALIZED_PIN || backwardPin == UNINITIALIZED_PIN)
        {
            logger->log(Level::Error, 
                      "[%s] Не заданы пины для насоса", 
                      getActuatorName().c_str());
            return false;
        }
        
        pinMode(forwardPin, OUTPUT);
        pinMode(backwardPin, OUTPUT);
        
        digitalWrite(forwardPin, LOW);
        digitalWrite(backwardPin, LOW);
        
        initialized = true;
        isOn = false;
        
        return true;
    }
    
    // Включить насос по умолчанию
    bool PumpR385::turnOn()
    {
        return turnOn(isForwardDirection);
    }
    
    // Включить насос в указанном направлении
    bool PumpR385::turnOn(bool forwardDirection)
    {
        if (!initialized)
        {
            logger->log(Level::Error, 
                      "[%s] Попытка включить насос до инициализации", 
                      getActuatorName().c_str());
            return false;
        }

        if (isOn)
        {
            logger->log(Level::Warning, 
                      "[%s] Попытка включить насос, но он уже включен", 
                      getActuatorName().c_str());
            return true;
        }
        
        // Запоминаем направление
        isForwardDirection = forwardDirection;
        
        logger->log(Level::Farm, 
                  "[%s] Включение насоса, направление: %s", 
                  getActuatorName().c_str(), 
                  isForwardDirection ? "вперед" : "назад");
        

        digitalWrite(forwardPin, LOW);
        digitalWrite(backwardPin, LOW);
        
        // Включаем нужное направление
        if (isForwardDirection)
        {
            digitalWrite(forwardPin, HIGH);
            digitalWrite(backwardPin, LOW);
        }
        else
        {
            digitalWrite(forwardPin, LOW);
            digitalWrite(backwardPin, HIGH);
        }
        
        isOn = true;
        lastUpdateTime = millis();
        
        return true;
    }
    
    bool PumpR385::turnOff()
    {
        if (!initialized)
        {
            if (logger)
            {
                logger->log(Level::Error, 
                        "[%s] Попытка выключить насос до инициализации", 
                        getActuatorName().c_str());
            }
            return false;
        }

        if (!isOn)
        {
            if (logger)
            {
                logger->log(Level::Warning, 
                        "[%s] Попытка выключить насос, но он уже выключен", 
                        getActuatorName().c_str());
            }
            return true;
        }

        if (logger)
        {
            logger->log(Level::Info, "[%s] Выключение насоса", getActuatorName().c_str());
        }
        
        digitalWrite(forwardPin, LOW);
        digitalWrite(backwardPin, LOW);
        
        isOn = false;
        lastUpdateTime = millis();
        
        return true;
    }
    
    bool PumpR385::getDirection() const
    {
        return isForwardDirection;
    }
    
    // Изменить направление работы
    bool PumpR385::setDirection(bool forwardDirection)
    {
        // Если насос работает и направление меняется, перезапускаем его
        if (isOn && isForwardDirection != forwardDirection)
        {
            turnOff();
            return turnOn(forwardDirection);
        }
        
        // Просто меняем направление, если насос не работает
        isForwardDirection = forwardDirection;
        return true;
    }
} 

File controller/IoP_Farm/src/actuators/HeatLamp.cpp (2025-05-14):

#include "actuators/HeatLamp.h"

namespace farm::actuators
{
    using namespace farm::log;
    using namespace farm::config::actuators;
    using namespace farm::config::sensors::calibration; 
               
    HeatLamp::HeatLamp(std::shared_ptr<log::ILogger> logger, int8_t controlPin)
        : controlPin(controlPin)
    {
        this->logger = logger;
        
        setActuatorName(names::HEATLAMP);
        setActuatorType(types::HEATER);
    }
    
    HeatLamp::~HeatLamp()
    {
        if (isOn)
        {
            turnOff();
        }
    }
    
    bool HeatLamp::initialize()
    {
        if (controlPin == UNINITIALIZED_PIN)
        {
            logger->log(Level::Error, 
                       "[%s] Не задан пин для лампы нагрева", 
                       getActuatorName().c_str());
            return false;
        }
        
        pinMode(controlPin, OUTPUT);
        
        digitalWrite(controlPin, LOW);
        
        initialized = true;
        isOn = false;
        
        return true;
    }
    
    bool HeatLamp::turnOn()
    {
        if (!initialized)
        {
            logger->log(Level::Error, 
                       "[%s] Попытка включить лампу нагрева до инициализации", 
                       getActuatorName().c_str());
            return false;
        }

        if (isOn)
        {
            logger->log(Level::Warning, 
                       "[%s] Попытка включить лампу нагрева, но она уже включена", 
                       getActuatorName().c_str());
            return true;
        }
        
        logger->log(Level::Farm, 
                   "[%s] Включение лампы нагрева", 
                   getActuatorName().c_str());
        
        digitalWrite(controlPin, HIGH);
        
        isOn = true;
        lastUpdateTime = millis();
        
        return true;
    }
    
    bool HeatLamp::turnOff()
    {
        if (!initialized)
        {
            logger->log(Level::Error, 
                       "[%s] Попытка выключить лампу нагрева до инициализации", 
                       getActuatorName().c_str());
            return false;
        }

        if (!isOn)
        {
            logger->log(Level::Warning, 
                       "[%s] Попытка выключить лампу нагрева, но она уже выключена", 
                       getActuatorName().c_str());
            return true;
        }
        
        logger->log(Level::Farm, 
                   "[%s] Выключение лампы нагрева", 
                   getActuatorName().c_str());
        
        digitalWrite(controlPin, LOW);
        
        isOn = false;
        lastUpdateTime = millis();
        
        return true;
    }
} 

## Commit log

2025-05-14 Добавил репозиторий для проекта по ФФ. Со схемой подключения и всем необходимым
    [HC-SR04_holder.stl, farmbox.stl, handhold.stl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]
2025-05-15 Refactor irrigation constants and enhance MQTT command handling
    - Updated DEFAULT_MIN_WATER_LEVEL to 5.0f for improved irrigation control.
    - Adjusted VOLUME_CHECK_INTERVAL_S to 0.1 seconds for more frequent water volume checks.
    - Increased IRRIGATION_TIMEOUT_SEC to 20 seconds for better timeout management.
    - Reduced MQTT_LOG_SEND_INTERVAL to 500 milliseconds for faster log transmission.
    - Added error logging for unknown MQTT topics and improved handling of FARM_ON command in mqtt_manager.cpp.
    [constants.h, mqtt_manager.cpp]
2025-05-15 Remove unused image file and update README to reference new image path
    - Deleted obsolete image file 'image.png'.
    - Updated README to link to 'Appearance_old.png' instead of the removed image.
    [Калибровка УЗ датчика.xlsx]
2025-05-17 Заменил app на включение модуля
